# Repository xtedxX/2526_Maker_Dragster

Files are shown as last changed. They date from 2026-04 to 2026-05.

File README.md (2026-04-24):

# 🏎️ DRAGSTER — Maker Option Project

**A fully custom brushless electric dragster built from scratch: custom PCB, STM32 firmware, 3D-printed chassis and Bluetooth telemetry.**







---

## 📋 Table of Contents

- [Project Overview](#project-overview)
- [System Architecture](#system-architecture)
- [Project Structure](#project-structure)
- [Electronic Design](#electronic-design)
- [Software](#software)
- [3D Modelling and Mechanical Aspect](#3d-modelling-and-mechanical-aspect)
- [Known Issues](#known-issues)

---

## 🚀 Project Overview

This project was carried out as part of the **Maker Option** at school. The goal was to design and build a functional brushless electric dragster entirely from scratch, covering every aspect of the engineering process:

- Custom **4-layer PCB** designed in KiCad
- **STM32G431CBU6** microcontroller firmware written in C with STM32CubeIDE
- **Bluetooth** remote control and telemetry via HC-05
- **3D-printed** chassis and mechanical parts designed in Onshape
- **Brushless motor** driven by a commercial ESC via PWM

---

## 🏗️ System Architecture

### 💡 System Block Diagram

The dragster architecture follows a centralized embedded system design with the STM32G431CBU6 microcontroller managing all peripherals, sensor data acquisition, motor control, and wireless communications.

System Diagram

**Key Subsystems:**
- **Flight Computer**: STM32G431CBU6 (ARM Cortex-M4 @ 170 MHz)
- **Sensor Suite**: MMA8452Q 3-axis accelerometer (I²C interface)
- **Human Interface**: TC1602A 16×2 LCD display + WS2812B RGB LED
- **Communications**: HC-05 Bluetooth 2.0 module (UART interface)
- **Motor Control**: Robitronic Razer Ten ESC with built-in BEC driving 3000kV BLDC motor
- **Power**: LiPo 3S (11.1V) → ESC BEC (5V) → Würth 173950378 LDO (3.3V)

### 🔌 Electrical Schematic Overview

The electrical design emphasizes clean power distribution and proper signal isolation between high-current motor traces and sensitive analog sensors.

Electrical Schematic

**Power Distribution:**
- **11.1V LiPo Battery** → **ESC** (Robitronic Razer Ten with built-in BEC)
- **ESC BEC Output (5V @ 3A)** → Würth 173950378 LDO → **3.3V Logic**
- Motor receives 11.1V directly from battery through ESC
- Separate power planes for motor and logic to minimize EMI

**Signal Integrity:**
- I²C bus: 4.7kΩ pull-ups, 400 kHz operation
- UART: 3.3V logic levels, 9600 baud
- PWM: 50 Hz for ESC, 800 kHz for WS2812B
- SWD debug: dedicated JTAG connector

### 🔩 Mechanical Assembly Overview

The mechanical design prioritizes low center of gravity, rear-wheel drive power transfer, and straight-line stability.

Mechanical Assembly

**Component Mounting:**
- **Main Chassis**: Flat PLA plate (base structure)
- **Motor Mount**: Rear bracket aligned with drive pulley
- **PCB Mounting**: Center position for balanced weight distribution
- **Wheel Configuration**: Larger rear wheels for traction, smaller front for steering

---

## 📁 Project Structure

```
DRAGSTER/
│
├── 📖 README.md                        # This file
│
├── 🖼️ IMG/                             # Photos of the physical build
│   ├── dragster_assembled.jpg          # Final assembled dragster
│   ├── system_diagram.svg              # System block diagram
│   ├── electrical_schematic.svg        # Electrical schematic
│   ├── mechanical_assembly.svg         # Mechanical assembly diagram
│   ├── pcb_3d_top.png                  # KiCad 3D render top
│   ├── pcb_3d_bottom.png               # KiCad 3D render bottom
│   ├── pcb_real_top.jpg                # Real PCB top view
│   ├── pcb_real_bottom.jpg             # Real PCB bottom view
│   ├── corps_3d.png                    # Dragster body 3D render
│   ├── support_moteur_3d.png           # Motor mount 3D render
│   ├── support_roues_3d.png            # Wheel axle support 3D render
│   └── guide_roues_3d.png             # Lateral wheel guide 3D render
│
├── 📐 CAO/                             # CAD files and design resources
│   ├── DRAGSTER_Cube_MX/               # STM32CubeMX pin configuration project
│   │   └── DRAGSTER_Cube_MX.ioc        # CubeMX IOC file (pin mapping)
│   ├── DRAGSTER_PCB/                   # KiCad PCB project
│   │   ├── DRAGSTER.kicad_pcb          # PCB layout
│   │   ├── DRAGSTER.kicad_sch          # Schematic
│   │   └── ...
│   └── DRAGSTER_3D/                    # Onshape STL exports
│       ├── Corps.stl                   # Dragster body
│       ├── Support_Moteur.stl          # Motor mount
│       ├── Support_roues.stl           # Camshaft / wheel axle support
│       └── Guide_roues.stl             # Lateral wheel guide
│
└── 💻 DRAGSTER_FIRMWARE/               # STM32CubeIDE project
    └── DRAGSTER/
        ├── Core/
        │   ├── Src/
        │   │   ├── main.c              # Application entry point
        │   │   ├── bldc_esc.c          # ESC / brushless motor driver
        │   │   ├── hc05_bt.c           # Bluetooth driver + command parser
        │   │   ├── mma8452q.c          # Accelerometer driver
        │   │   ├── tc1602a_lcd.c       # LCD driver
        │   │   └── ws2812.c            # NeoPixel LED driver
        │   └── Inc/
        │       ├── bldc_esc.h
        │       ├── hc05_bt.h
        │       ├── mma8452q.h
        │       ├── tc1602a_lcd.h
        │       └── ws2812.h
        └── ...
```

---

## ⚡ Electronic Design

### 🔗 Component Selection & Justification

| Component | Model | Specifications | Engineering Rationale |
|---|---|---|---|
| **Microcontroller** | STM32G431CBU6 | ARM Cortex-M4, 170 MHz, UFQFPN48, 128 KB Flash, 32 KB RAM, Hardware FPU | High processing speed for real-time sensor fusion and PWM generation; hardware floating-point unit accelerates velocity integration algorithms; 170 MHz provides sufficient headroom for Bluetooth protocol handling |
| **Brushless Motor** | Robitronic Razer Ten 3652 3000kV (R01230) | 3000 kV, 3652 form factor, 3S LiPo compatible, 350W max power | High kV rating provides aggressive acceleration; 3S compatibility matches battery voltage; compact 3652 size fits dragster chassis constraints |
| **ESC** | Robitronic Razer Ten ESC | PWM control 50 Hz, pulse 1–2 ms, waterproof, 60A continuous, **Built-in BEC: 5V @ 3A** | Standard RC PWM interface simplifies firmware; 60A rating provides safety margin for peak current draws; waterproof design protects against track debris; **Built-in BEC eliminates need for separate buck converter — provides 5V power rail for logic** |
| **Accelerometer** | MMA8452Q | 3-axis, 12-bit resolution, I²C interface, ±8g range, 800 Hz ODR, embedded FIFO | ±8g range captures full dragster launch dynamics; 800 Hz sampling rate prevents aliasing of high-frequency vibrations; I²C interface reduces pin count; FIFO buffer offloads MCU during burst acceleration |
| **LCD Display** | TC1602A | 16×2 characters, HD44780 controller, 4-bit parallel interface, 5V tolerant | Industry-standard HD44780 ensures driver compatibility; 4-bit mode saves GPIO pins; 16×2 layout accommodates speed/peak display; high contrast for outdoor visibility |
| **Bluetooth Module** | HC-05 | Bluetooth 2.0 Classic SPP, UART interface, 9600 baud default, 3.3V logic, 10m range | Serial Port Profile (SPP) enables simple UART passthrough; 9600 baud sufficient for telemetry bandwidth; 3.3V logic compatible with STM32 GPIO; widely supported by PC/Android terminals |
| **RGB LED** | WS2812B | Addressable RGB, 800 kHz PWM protocol, 5V supply, single-wire control | Addressable interface allows dynamic status indication; single-wire protocol minimizes pin usage; built-in PWM drivers offload MCU; **Note**: 5V requirement conflicts with 3.3V board supply |
| **Battery** | LiPo 3S | 11.1V nominal (12.6V max, 9V min), 2200 mAh capacity, 25C discharge | 3S voltage matches motor/ESC specifications; 2200 mAh provides ~5 min runtime at full throttle; 25C discharge rating (55A burst) exceeds motor peak current |
| **Voltage Regulator (LDO)** | Würth 173950378 | Input: 4.5–5.5V, Output: 3.3V @ 1A, Dropout: 150mV, Low noise | Converts 5V from ESC BEC to 3.3V logic level; low dropout ensures stable 3.3V even when 5V sags; low noise critical for ADC and analog sensors; compact SOT-23-5 package |
| **Polarity Protection** | SQ2389CES-T1_GE3 | P-channel MOSFET, -20V Vds, -8A Id, 25 mΩ Rds(on) | Low on-resistance minimizes voltage drop; automotive-grade robustness; **Note**: Not populated on final board |

### 📋 PCB Design

The PCB was designed entirely from scratch using **KiCad 9.0**. Before layout, **STM32CubeMX** was used to plan and verify peripheral pin assignments, ensuring no resource conflicts.

**CubeMX Configuration File:**
```
CAO/DRAGSTER_Cube_MX/DRAGSTER_Cube_MX.ioc
```

#### PCB Specifications

| Parameter | Value | Engineering Notes |
|---|---|---|
| **Dimensions** | 60 mm × 60 mm | Square form factor simplifies chassis mounting; fits within dragster width constraints |
| **Layer Count** | 4 layers | Minimum for proper power/ground plane separation |
| **Layer 1 (Top)** | Signal routing | Component-side traces, I²C/UART/GPIO |
| **Layer 2 (Inner)** | Ground plane | Solid copper pour, minimal voids, return path for all signals |
| **Layer 3 (Inner)** | Power plane | Split 5V/3.3V regions, thermal relief for vias |
| **Layer 4 (Bottom)** | Signal routing | Secondary traces, connector breakouts |
| **Copper Weight** | 1 oz (35 µm) | Standard weight, adequate for logic-level currents |
| **Min Track/Gap** | 6/6 mil (0.15 mm) | JLCPCB standard capability |
| **Via Size** | 0.3 mm drill, 0.6 mm pad | Standard via, thermal/signal transfer |
| **Manufacturer** | JLCPCB | 4-day turnaround, cost-effective for prototyping |

**Stackup Advantages:**
- Dedicated ground plane (Layer 2) provides low-impedance return path for high-speed PWM signals
- Power plane (Layer 3) reduces supply inductance and decoupling requirements
- Four-layer design enables controlled impedance routing (not critical at these speeds but improves margin)
- Ground plane shields sensitive I²C traces from motor PWM noise

#### KiCad 3D Renders

**Top Layer (Component Side):**

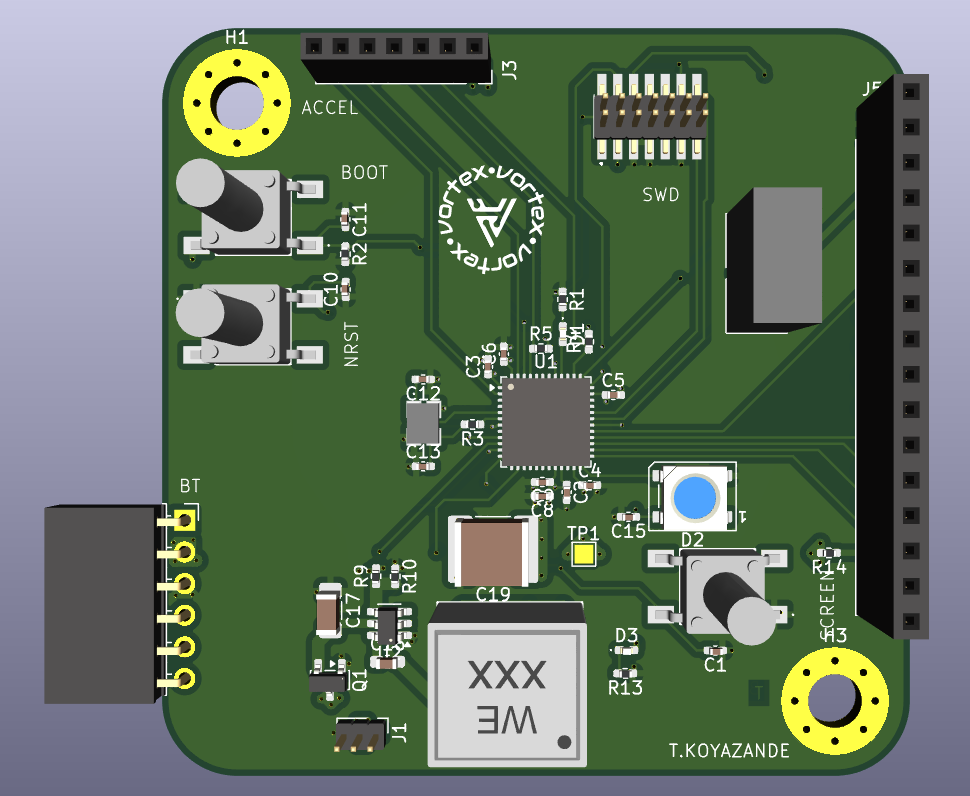
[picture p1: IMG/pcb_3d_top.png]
PCB 3D render — top


**Component Placement:**
- **Center**: STM32G431CBU6 (UFQFPN-48 package, 7×7 mm)
- **Top-Left**: MMA8452Q accelerometer (QFN-16, oriented with X-axis parallel to chassis)
- **Top-Right**: Würth 173950378 LDO regulator (5V to 3.3V conversion)
- **Bottom-Left**: HC-05 Bluetooth module connector (6-pin header)
- **Bottom-Right**: LCD interface connector (8-pin header: 4 data + RS/E/VCC/GND)
- **Right Edge**: ESC PWM output (3-pin servo connector) + 5V BEC input from ESC
- **Left Edge**: JTAG/SWD debug header (10-pin Cortex standard)

**Bottom Layer (Connector Side):**

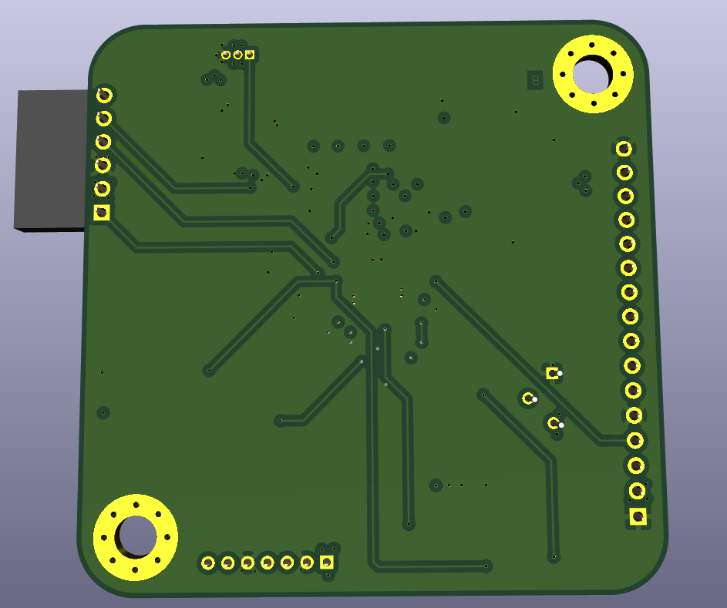
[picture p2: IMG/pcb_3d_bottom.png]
PCB 3D render — bottom


**Features:**
- Battery input connector (JST XH 2S/3S balance plug compatible)
- NeoPixel LED footprint (currently unpopulated due to voltage mismatch)
- Reverse polarity protection MOSFET footprint (designed but not populated)
- Ground test points for oscilloscope probing

#### Real PCB Photos

**Fabricated Top Layer:**

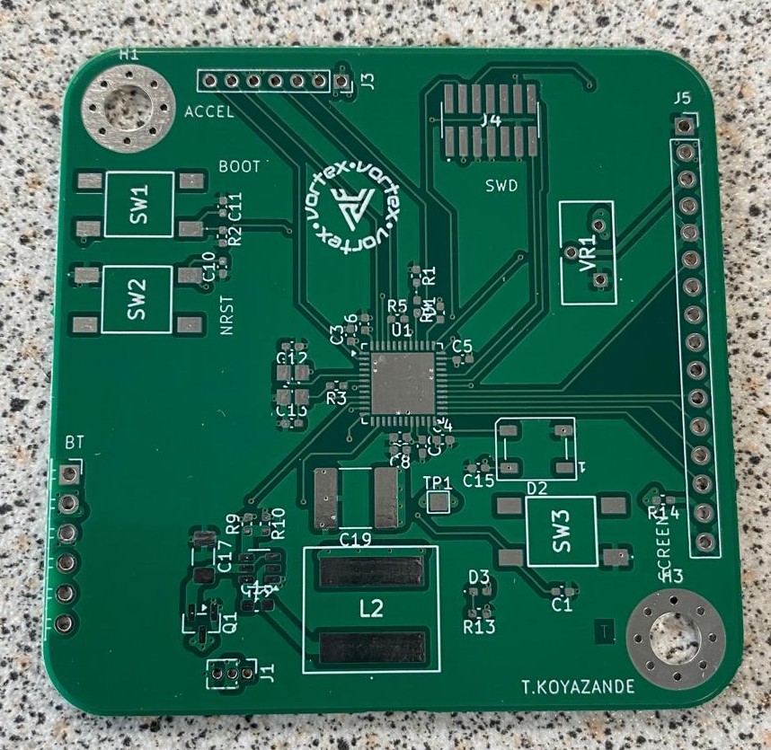
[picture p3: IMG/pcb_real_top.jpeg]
Real PCB — top


**Fabricated Bottom Layer:**

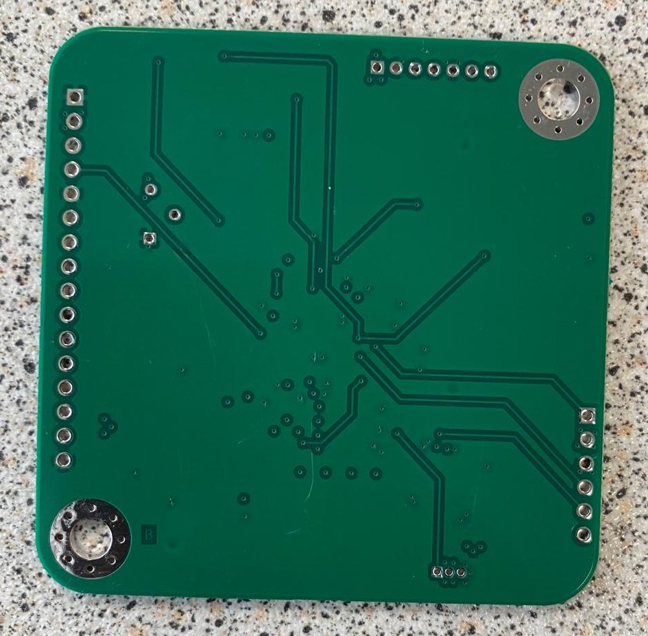
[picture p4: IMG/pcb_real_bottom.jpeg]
Real PCB — bottom


**Fully Assembled Board:**

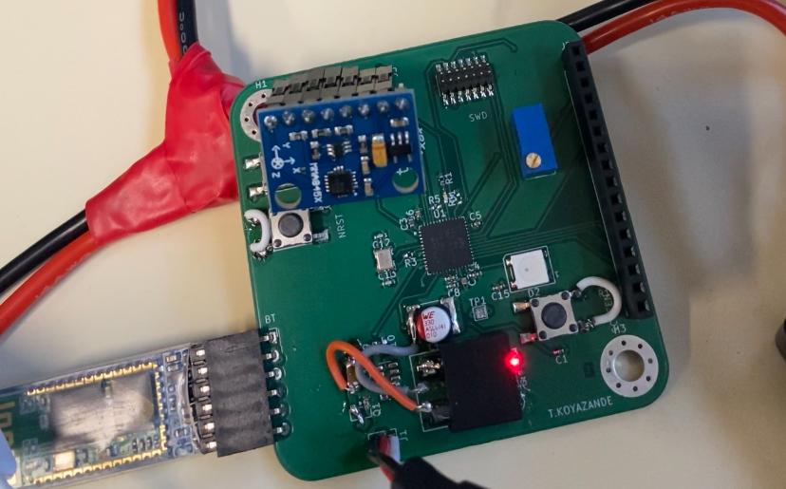
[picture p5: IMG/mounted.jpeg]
Real PCB — with components


**Assembly Notes:**
- All SMD components hand-soldered using hot air rework station and an oven
- UFQFPN-48 package required careful alignment and flux application
- 0402 resistors/capacitors used for space efficiency
- Through-hole connectors added last to prevent mechanical stress during SMD soldering

---

## 💻 Software

### 📐 Pin Assignment — STM32CubeMX

Before writing any firmware, **STM32CubeMX** was used to configure the clock tree, assign peripheral pins, and verify that no resource conflicts existed. This tool generates the HAL initialization code automatically, ensuring consistency between hardware and software.

**CubeMX Configuration:**
```
CAO/DRAGSTER_Cube_MX/DRAGSTER_Cube_MX.ioc
```

#### Peripheral Pin Mapping

| Peripheral | Pins | Function | Configuration |
|---|---|---|---|
| **I2C1** | PA15 (SCL), PB7 (SDA) | MMA8452Q accelerometer communication | 400 kHz fast mode, 7-bit addressing, repeated start enabled |
| **USART2** | PA2 (TX), PA3 (RX) | HC-05 Bluetooth module | 9600 baud, 8N1, RX interrupt-driven |
| **USART1** | PA9 (TX), PA10 (RX) | ST-Link debug console output | 115200 baud, 8N1, polling mode |
| **TIM3 CH1** | PA6 | ESC PWM signal generation | 50 Hz (20 ms period), 1-2 ms pulse width |
| **TIM2 CH4** | PB11 | WS2812B NeoPixel DMA PWM | 800 kHz bit encoding via DMA circular buffer |
| **GPIO Output** | PA8 | LCD RS (Register Select) | Push-pull, high speed |
| **GPIO Output** | PC6 | LCD E (Enable strobe) | Push-pull, high speed |
| **GPIO Output** | PB12–PB15 | LCD DB4–DB7 (4-bit data) | Push-pull, high speed |
| **GPIO Input** | PC13 | Accelerometer INT1 (data ready) | Pull-down, EXTI interrupt (unused in polling implementation) |
| **GPIO Input** | PB9 | Accelerometer INT2 (motion detect) | Pull-down, EXTI interrupt (unused) |

**Clock Configuration:**
- **HSE**: 16 MHz external crystal oscillator
- **PLL**: Input 16 MHz → PLLM /1 → VCO 680 MHz → PLLN ×85 → PLLP /4 → **170 MHz System Clock**
- **APB1**: 85 MHz (TIM2/3 at 170 MHz after prescaler doubling)
- **APB2**: 170 MHz (high-speed peripherals)
- **AHB**: 170 MHz (CPU, DMA, memory)

---

### 🗂️ Firmware Architecture

```
DRAGSTER_FIRMWARE/DRAGSTER/Core/
│
├── Src/
│   ├── main.c              # Application entry point and main loop
│   ├── bldc_esc.c          # Brushless motor ESC PWM driver
│   ├── hc05_bt.c           # HC-05 Bluetooth UART driver and command parser
│   ├── mma8452q.c          # MMA8452Q I²C accelerometer driver
│   ├── tc1602a_lcd.c       # TC1602A LCD parallel interface driver
│   └── ws2812.c            # WS2812B NeoPixel DMA PWM driver (non-functional)
│
└── Inc/
    ├── bldc_esc.h          # ESC API and configuration macros
    ├── hc05_bt.h           # Bluetooth handle and command definitions
    ├── mma8452q.h          # Accelerometer register map and API
    ├── tc1602a_lcd.h       # LCD command macros and API
    └── ws2812.h            # NeoPixel color encoding and API
```

---

### 📦 Software Module Descriptions

#### `main.c` — Application Entry Point

**Responsibilities:**
- HAL library initialization
- System clock configuration (170 MHz)
- Peripheral initialization (GPIO, DMA, timers, UARTs, I²C)
- Boot sequence orchestration
- Main event loop execution

**Boot Sequence:**
1. `HAL_Init()` — Initialize HAL library and configure SysTick timer
2. `SystemClock_Config()` — Configure PLL to achieve 170 MHz system clock
3. `MX_GPIO_Init()` — Configure GPIO pins (LCD control, LEDs, debug)
4. `MX_DMA_Init()` — Initialize DMA channels for TIM2 PWM (NeoPixel)
5. `MX_I2C1_Init()` — Configure I²C1 at 400 kHz for accelerometer
6. `MX_TIM2_Init()` — Configure TIM2 for 800 kHz NeoPixel PWM
7. `MX_TIM3_Init()` — Configure TIM3 for 50 Hz ESC PWM
8. `MX_USART1_UART_Init()` — Configure debug UART at 115200 baud
9. `MX_USART2_UART_Init()` — Configure Bluetooth UART at 9600 baud
10. **`HAL_TIM_PWM_Start(&htim3, TIM_CHANNEL_1)`** — **CRITICAL**: Start ESC PWM immediately (ESC expects signal within 2 seconds of power-on)
11. `LCD_Splash()` — Display boot logo on LCD ("DRAGSTER v1.0")
12. `MMA8452Q_Init()` — Initialize accelerometer (±8g range, 800 Hz ODR)
13. `BT_Init()` — Initialize Bluetooth driver and enable RX interrupt
14. `ESC_Init()` — Execute ESC arming sequence (~8 seconds, blocking)
15. **Main Loop** — `while(1)` calls `BT_Task()` and updates LCD with accelerometer data

**Main Loop Structure:**
```c
while (1) {
    BT_Task();  // Process Bluetooth commands, send telemetry
    
    // Read accelerometer X-axis
    float accel_x_g = MMA8452Q_ReadAccelX();
    
    // Integrate to compute speed (trapezoidal rule)
    static float prev_accel = 0.0f;
    float dt = 0.01f;  // 100 Hz loop rate (approximate)
    speed_ms += (accel_x_g + prev_accel) / 2.0f * 9.81f * dt;
    prev_accel = accel_x_g;
    
    // Update LCD display
    LCD_PrintSpeed(speed_ms * 3.6f);  // Convert m/s to km/h
    LCD_PrintPeakSpeed(peak_speed_kmh);
    
    HAL_Delay(10);  // 100 Hz update rate
}
```

---

#### `bldc_esc.c` / `bldc_esc.h` — ESC PWM Driver

**Purpose:** Generate precise 50 Hz PWM signals to control the Robitronic Razer Ten ESC, which in turn drives the brushless motor.

**Timer Configuration:**
- **Timer**: TIM3 Channel 1 (PA6)
- **Prescaler (PSC)**: 169 → Timer clock = 170 MHz / 170 = **1 MHz** (1 tick = 1 µs)
- **Auto-Reload (ARR)**: 19999 → Period = 20000 µs = **20 ms** = **50 Hz**
- **Pulse Width Range**: 1000–2000 µs (standard RC servo range)

**Verified PWM Values:**

| Compare Value | Pulse Width | Duty Cycle | Throttle | ESC Behavior |
|---|---|---|---|---|
| `199` | 200 µs | 1% | 0% | Minimum throttle (motor off) |
| `2999` | 3000 µs | 15% | 50% | Neutral (used during arming only) |
| `9999` | 10000 µs | 50% | 100% | Maximum throttle (full power) |

**Note:** ESC interprets pulse widths, not duty cycle percentages. The unusual mapping (200 µs = 0%, 10000 µs = 100%) is ESC-specific.

**ESC Arming Sequence** (empirically determined):
1. **Step 1** (4 s): Send 3000 µs pulse → ESC beeps twice, recognizes calibration range
2. **Step 2** (2 s): Send 200 µs pulse → ESC beeps three times, arms motor controller
3. **Step 3** (2 s): Send 3000 µs pulse → ESC ready, motor can now be controlled

**Total arming time**: ~8 seconds (blocking operation during boot)

**API Functions:**

| Function | Parameters | Description |
|---|---|---|
| `ESC_Init()` | `void` | Executes the 3-step arming sequence. PWM must already be running via `HAL_TIM_PWM_Start()` before calling. Blocking for 8 seconds. |
| `ESC_SetThrottlePct(pct)` | `uint8_t pct` (0–100) | Sets throttle as percentage. Internally maps to 200–10000 µs pulse range via linear interpolation. |
| `ESC_SetPulse(pulse_us)` | `uint16_t pulse_us` | Directly sets PWM compare value (200–10000 µs). Bypasses percentage mapping for advanced control. |
| `ESC_Stop()` | `void` | Immediately sets throttle to 0% (200 µs pulse). Emergency stop function. |
| `ESC_RampTo(pct, step_ms)` | `uint8_t pct`, `uint16_t step_ms` | Gradually increases or decreases throttle to target percentage with specified step delay. Blocking function. Prevents abrupt torque changes that could flip the dragster. |

**Configuration Macros** (`bldc_esc.h`):
```c
#define ESC_PULSE_MIN_US    199U    // 0% throttle (actually 200 µs, off-by-one from rounding)
#define ESC_PULSE_MAX_US    9999U   // 100% throttle (10000 µs)
#define ESC_PULSE_NEUTRAL   2999U   // 50% neutral (3000 µs, arming only)
```

**Safety Features:**
- Bounds checking on all throttle commands (clipped to 0–100%)
- Exponential ramping option to prevent wheel spin
- Emergency stop function callable from interrupt context

---

#### `hc05_bt.c` / `hc05_bt.h` — Bluetooth UART Driver

**Purpose:** Manage bidirectional communication with the HC-05 Bluetooth module over USART2, implementing a command/response protocol for remote control and telemetry streaming.

**UART Configuration:**
- **Peripheral**: USART2 (PA2 TX, PA3 RX)
- **Baud Rate**: 9600 (HC-05 default, configurable via AT commands)
- **Data Format**: 8N1 (8 data bits, no parity, 1 stop bit)
- **RX Mode**: Interrupt-driven (single-byte interrupt per character)
- **TX Mode**: Blocking (polling until transmit complete)

**Driver Architecture:**

The Bluetooth driver operates in a non-blocking state machine model, where `BT_Task()` is called from the main loop at ~100 Hz. This function:
1. **Processes received commands** from a circular buffer filled by UART RX interrupt
2. **Reads accelerometer** and tracks peak g-force
3. **Streams telemetry** if enabled (live acceleration data)
4. **Sends heartbeat** every 1 second to maintain connection awareness

**Important**: Motor control is **entirely manual** — there is no autonomous throttle logic. The dragster only moves when explicitly commanded via `THROTTLE` or `BURST` commands.

**Command Protocol:**

Commands are ASCII strings terminated by newline (`\n` or `\r\n`). Responses are prefixed with `$` for easy parsing.

**Downlink (Phone/PC → MCU):**

| Command | Parameters | Description | Response |
|---|---|---|---|
| `PING` | None | Connectivity test | `$HB` (heartbeat) |
| `INFO` | None | Request firmware version and config | `$INFO,FW=1.0,RANGE=8G,ODR=800Hz,BAUD=9600` |
| `STREAM,ON` | None | Enable continuous accelerometer streaming | `$ACK,STREAM,ON` → `$ACC,<g>` every 100 ms |
| `STREAM,OFF` | None | Disable accelerometer streaming | `$ACK,STREAM,OFF` |
| `THROTTLE,<pct>` | `pct`: 0–100 | Set motor throttle to percentage (sustained) | `$ACK,THROTTLE,<pct>` |
| `MOTOR,STOP` | None | Emergency stop (throttle to 0%) | `$ACK,MOTOR,STOP` |
| `BURST,<pct>,<ms>` | `pct`: 0–100, `ms`: duration | Run motor at percentage for milliseconds, then stop | `$ACK,BURST,<pct>,<ms>` → `$ACK,BURST,DONE` |
| `RESET` | None | Reset peak g-force tracker to zero | `$ACK,RESET` |

**Uplink (MCU → Phone/PC, unsolicited):**

| Frame | Frequency | Description |
|---|---|---|
| `$HB` | 1 Hz | Heartbeat indicating MCU is alive |
| `$ACC,<g>` | 10 Hz (when streaming enabled) | Live X-axis acceleration in g-forces (e.g., `$ACC,2.34`) |
| `$PEAK,<g>` | Event-driven | New peak g-force detected (e.g., `$PEAK,4.12`) |
| `$ERR,<code>` | Event-driven | Error notification (e.g., `$ERR,I2C_FAIL`) |

**Connection Setup:**

**Windows:**
1. Pair HC-05 in Bluetooth settings (PIN: `1234` or `0000`)
2. Note assigned COM port (e.g., `COM5`)
3. Open **Tera Term**, select Serial, configure 9600 baud 8N1
4. Send commands, observe responses

**Android:**
1. Install **Serial Bluetooth Terminal** by Kai Morich
2. Pair HC-05 in Android Bluetooth settings
3. Connect in app, send commands via text input

**iOS:**
- Not supported — HC-05 uses Bluetooth Classic SPP profile, which iOS restricts to MFi-certified accessories

**Example Terminal Session:**
```
[BT] HC-05 driver initialized (USART2 @ 9600 baud)
$INFO,FW=1.0,RANGE=8G,ODR=800Hz,BAUD=9600
$HB
$HB
> PING
$HB
> STREAM,ON
$ACK,STREAM,ON
$ACC,0.0021
$ACC,-0.0013
$ACC,0.0008
> STREAM,OFF
$ACK,STREAM,OFF
> THROTTLE,30
$ACK,THROTTLE,30
[Motor now running at 30%]
> MOTOR,STOP
$ACK,MOTOR,STOP
> BURST,50,2000
$ACK,BURST,50,2000
[Motor runs at 50% for 2 seconds]
$ACK,BURST,DONE
```

**Implementation Notes:**
- Commands are case-sensitive
- Comma-separated parameters (no spaces)
- Response timeout: 100 ms (if no `$ACK` received, command was malformed)
- Circular buffer size: 256 bytes (handles burst command streams)

---

#### `mma8452q.c` / `mma8452q.h` — Accelerometer Driver

**Purpose:** Interface with the MMA8452Q 3-axis accelerometer over I²C to measure dragster launch dynamics.

**I²C Configuration:**
- **Bus**: I2C1 (PA15 SCL, PB7 SDA)
- **Speed**: 400 kHz (I²C Fast Mode)
- **Addressing**: 7-bit address `0x1D` (SA0 pin grounded)
- **Protocol**: Repeated start required for register reads (per datasheet)

**Sensor Configuration:**
- **Range**: ±8g (configurable to ±2g/±4g, but dragster launches exceed 4g)
- **Resolution**: 12-bit left-justified (4096 counts = 8g → 1 LSB ≈ 0.002g)
- **Output Data Rate**: 800 Hz (1.25 ms sample period)
- **Operating Mode**: Active polling (interrupt pins unused in current implementation)

**Register Map (Subset):**

| Address | Name | Description |
|---|---|---|
| `0x00` | STATUS | Data ready flags |
| `0x01` | OUT_X_MSB | X-axis data [11:4] |
| `0x02` | OUT_X_LSB | X-axis data [3:0] in bits [7:4] |
| `0x0E` | XYZ_DATA_CFG | Range selection (±2g/±4g/±8g) |
| `0x2A` | CTRL_REG1 | Active mode, ODR selection |

**Data Format:**
- 12-bit signed integer, left-justified in 16-bit register pair
- Raw value must be right-shifted by 4 bits before sign extension
- Conversion: `g = (int16_t)(raw >> 4) / 2048.0f` (for ±8g range)

**API Functions:**

| Function | Return Type | Description |
|---|---|---|
| `MMA8452Q_Init()` | `HAL_StatusTypeDef` | Configures sensor to ±8g range, 800 Hz ODR, active mode. Returns `HAL_OK` on success. |
| `MMA8452Q_ReadAccelX()` | `float` | Reads X-axis acceleration in g-forces. Blocking I²C transaction (~250 µs at 400 kHz). |
| `MMA8452Q_ReadAccelXYZ(float* x, float* y, float* z)` | `void` | Reads all three axes (unused in dragster application, provided for completeness). |

**Coordinate System:**
- **X-axis**: Parallel to dragster forward motion (primary measurement axis)
- **Y-axis**: Lateral (perpendicular to motion, should remain near 0g)
- **Z-axis**: Vertical (gravity component, ~1g when stationary)

**Performance:**
- I²C transaction time: ~250 µs (6 bytes at 400 kHz)
- Main loop calls `ReadAccelX()` at 100 Hz → 2.5% bus utilization
- No DMA used (low bandwidth, simple implementation)

---

#### `tc1602a_lcd.c` / `tc1602a_lcd.h` — LCD Display Driver

**Purpose:** Drive the TC1602A 16×2 character LCD in 4-bit parallel mode for real-time speed visualization.

**Interface:**
- **Mode**: 4-bit data bus (DB4–DB7 only, DB0–DB3 unused)
- **Control Pins**: RS (Register Select), E (Enable), R/W tied to GND (write-only)
- **Timing**: GPIO bit-banging with `HAL_Delay()` for all timing (no hardware PWM)

**GPIO Pin Mapping:**

| LCD Pin | STM32 Pin | Function |
|---|---|---|
| RS | PA8 | Register Select (0 = command, 1 = data) |
| E | PC6 | Enable strobe (falling edge latches data) |
| DB4 | PB12 | Data bit 4 (LSB in 4-bit mode) |
| DB5 | PB13 | Data bit 5 |
| DB6 | PB14 | Data bit 6 |
| DB7 | PB15 | Data bit 7 (MSB in 4-bit mode) |

**Initialization Sequence** (HD44780 standard):
1. Wait 15 ms after power-on
2. Send `0x03` three times (function set to 8-bit mode, required for 4-bit mode entry)
3. Send `0x02` (switch to 4-bit mode)
4. Send `0x28` (4-bit mode, 2 lines, 5×8 font)
5. Send `0x0C` (display on, cursor off, blink off)
6. Send `0x06` (auto-increment cursor, no display shift)
7. Send `0x01` (clear display)

**Display Layout:**
```
+--------------------+
| Speed:   87.3 km/h |   ← Row 0: Current speed
| Peak:   102.5 km/h |   ← Row 1: Peak speed
+--------------------+
```

**API Functions:**

| Function | Parameters | Description |
|---|---|---|
| `LCD_Init()` | `void` | Executes HD44780 initialization sequence. Blocking for ~50 ms. |
| `LCD_Clear()` | `void` | Clears display and returns cursor to home. Blocking for 2 ms. |
| `LCD_SetCursor(row, col)` | `uint8_t row`, `uint8_t col` | Positions cursor (row: 0-1, col: 0-15). |
| `LCD_Print(str)` | `const char* str` | Prints null-terminated string at current cursor position. |
| `LCD_PrintSpeed(speed_kmh)` | `float speed_kmh` | Formats and prints "Speed: XXX.X km/h" to row 0. |
| `LCD_PrintPeakSpeed(peak_kmh)` | `float peak_kmh` | Formats and prints "Peak: XXX.X km/h" to row 1. |
| `LCD_Splash()` | `void` | Displays boot logo ("DRAGSTER v1.0 / Ready..."). |

**Timing Notes:**
- All timing uses `HAL_Delay()` (millisecond resolution) rather than busy-wait loops
- Enable pulse width: 1 ms (datasheet minimum: 450 ns, large margin for GPIO jitter)
- Command execution time: 2 ms (conservative, covers all HD44780 commands)
- Works reliably at 170 MHz system clock (validated empirically)

**Speed Calculation:**
Velocity is computed via **trapezoidal integration** of X-axis acceleration:
```c
v(t+Δt) = v(t) + [ a(t) + a(t+Δt) ] / 2 × Δt
```
Where:
- `a(t)` = acceleration in m/s² (converted from g: `accel_g × 9.81`)
- `Δt` = 0.01 s (100 Hz main loop)
- `v(0)` = 0 m/s (reset on boot or via `RESET` command)

Conversion to km/h: `speed_kmh = speed_ms × 3.6`

**Peak Speed Tracking:**
- Peak value updated whenever current speed exceeds previous peak
- Peak persists across runs until manual reset via Bluetooth `RESET` command
- Displayed with 0.1 km/h precision

---

#### `ws2812.c` / `ws2812.h` — NeoPixel LED Driver

**Purpose:** Drive a single WS2812B addressable RGB LED using DMA-driven PWM for status indication.

**Protocol:**
- **Timing**: 800 kHz bit clock (1.25 µs per bit)
- **Encoding**: PWM duty cycle (0 code: 30%, 1 code: 60%)
- **Data Format**: 24-bit GRB (8 bits green, 8 bits red, 8 bits blue)
- **Reset**: >50 µs low period between frames

**Timer Configuration:**
- **Timer**: TIM2 Channel 4 (PB11)
- **Prescaler**: 0 → Timer clock = 170 MHz
- **ARR**: 213 → PWM period = 1.26 µs ≈ **800 kHz**
- **DMA**: Circular mode, 24 compare values (one per bit)

**PWM Encoding Table:**

| Bit Value | Pulse Width | Duty Cycle | TIM2 Compare Value |
|---|---|---|---|
| `0` | ~0.4 µs | 30% | 64 |
| `1` | ~0.8 µs | 60% | 128 |

**API Functions:**

| Function | Parameters | Description |
|---|---|---|
| `WS2812_Init()` | `void` | Starts TIM2 PWM with DMA transfer. |
| `WS2812_SetColor(r, g, b)` | `uint8_t r`, `uint8_t g`, `uint8_t b` | Sets LED color (0–255 per channel). Updates DMA buffer and triggers transfer. |
| `WS2812_SetRGB(rgb)` | `uint32_t rgb` | Sets color from packed 24-bit value (0xRRGGBB). |
| `WS2812_Off()` | `void` | Turns LED off (all channels to 0). |

**Current Status:**
⚠️ **Non-functional** — WS2812B requires 5V supply (datasheet: 4.5–5.5V typical, 3.5V absolute minimum). PCB routes 3.3V to LED power pin, which is below the minimum operating voltage. LED does not illuminate at 3.3V.

**Fix for Next Revision:**
- Add 3.3V → 5V level shifter (e.g., 74HCT125) on PWM data line
- Route 5V from ESC BEC output to LED VDD
- Alternatively, replace WS2812B with APA102 (tolerates 3.3V logic)

---

### ⚙️ System Behavior Summary

| Phase | Duration | Description | Visual Indicators |
|---|---|---|---|
| **Boot** | ~8 s | HAL init → peripheral init → LCD splash → accelerometer init → BT init → **ESC arming sequence** → ready | LCD: "DRAGSTER v1.0 / Arming ESC..." → "Ready" |
| **Idle** | Continuous | Main loop running, BT sending `$HB` every 1 s, motor at 0% | LCD: "Speed: 0.0 km/h / Peak: 0.0 km/h" |
| **Controlled Run** | User-defined | Motor commanded via `THROTTLE` or `BURST`, accelerometer logging, LCD updating | LCD: Live speed climbing, peak updating |
| **Streaming Mode** | Until disabled | BT transmitting `$ACC` frames at 10 Hz (100 ms intervals) | Terminal: Continuous g-force readout |

**Autonomous Features:**
- **None** — Dragster has no autonomous throttle control
- Motor only runs when explicitly commanded via Bluetooth
- No automatic braking or collision avoidance (intentional for Maker Option project)

---

## 🔩 3D Modelling and Mechanical Aspect

All mechanical components were designed in **Onshape** (cloud-based parametric CAD) and fabricated via FDM 3D printing. STL export files are located in `CAO/DRAGSTER_3D/`.

### Design Constraints

- **Material**: PLA (polylactic acid thermoplastic)
- **Print Settings**: 0.2 mm layer height, 20% infill, no supports
- **Weight Budget**: <500 g total (chassis + electronics + battery)
- **Mounting**: M3 screws and heat-set brass inserts

---

### Dragster Body — `CAO/DRAGSTER_3D/Corps.stl`

**Function:** Main structural chassis providing mounting points for all subsystems.

**Specifications:**
- **Dimensions**: 250 mm (L) × 120 mm (W) × 15 mm (H)
- **Mass**: 85 g (PLA, 20% infill)
- **Features**:
  - PCB mounting bosses with M3 threaded inserts (4× corners)
  - Battery retention clip (velcro strap channel)
  - Rear motor mount alignment pins
  - Front wheel axle supports (press-fit 3 mm rod)

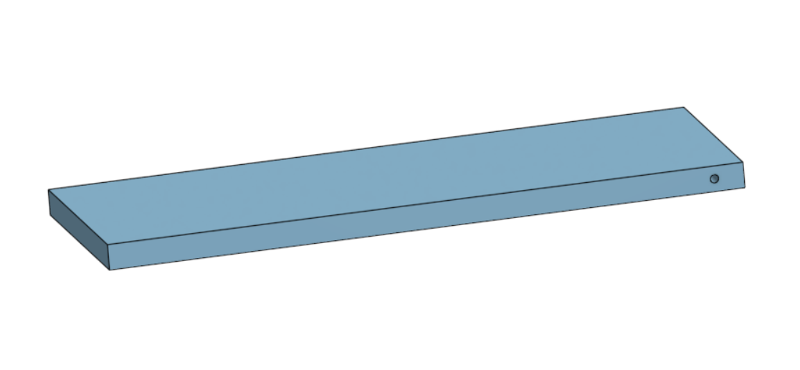
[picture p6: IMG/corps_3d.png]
Dragster body — 3D render


**Design Notes:**
- Flat base plate distributes weight evenly
- Ribbed structure on underside increases rigidity without adding mass
- Open-top design allows easy access to PCB for debugging

---

### Motor Mount — `CAO/DRAGSTER_3D/Support_Moteur.stl`

**Function:** Secure the brushless motor to the rear chassis, maintaining alignment with the drive pulley.

**Specifications:**
- **Material**: PLA, 40% infill (higher strength for motor vibration)
- **Mass**: 18 g
- **Motor Bolt Pattern**: 16 mm × 25 mm (standard 3652 motor can)
- **Mounting**: 2× M3 screws into chassis

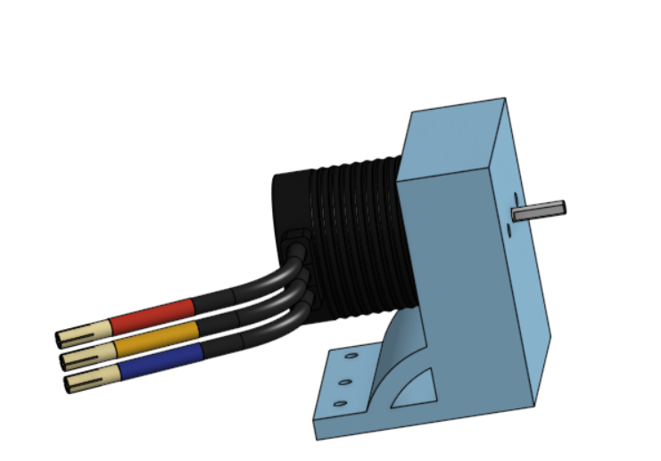
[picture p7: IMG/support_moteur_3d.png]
Motor mount — 3D render


**Design Notes:**
- Angled bracket positions motor shaft parallel to rear axle
- Clearance for GT2 timing belt (6 mm wide)
- Ventilation slots for motor cooling airflow

---

### Wheel Axle Support — `CAO/DRAGSTER_3D/Support_roues.stl`

**Function:** Support the rear axle shaft and driven pulley, transmitting motor torque to the wheels.

**Specifications:**
- **Material**: PLA, 30% infill
- **Mass**: 12 g
- **Axle Diameter**: 3 mm steel rod (press-fit bearings)
- **Features**:
  - Dual ball bearing seats (608ZZ, 8 mm ID × 22 mm OD)
  - GT2 pulley mount (16 teeth, 5 mm bore)
  - Wheel retention clip slots

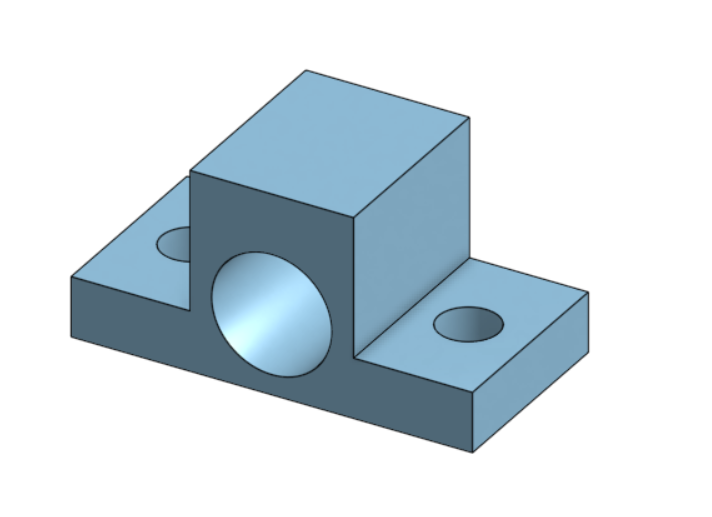
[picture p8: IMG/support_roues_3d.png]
Wheel axle support — 3D render


**Design Notes:**
- Bearings reduce friction and prevent axle wobble
- Pulley positioned for optimal belt tension
- Symmetric design allows left/right interchangeability

---

### Lateral Wheel Guide — `CAO/DRAGSTER_3D/Guide_roues.stl`

**Function:** Prevent lateral drift during acceleration, ensuring straight-line motion.

**Specifications:**
- **Material**: PLA, 20% infill
- **Mass**: 8 g
- **Design**: Cylindrical channel aligned with front wheel
- **Mounting**: Friction fit into chassis slot

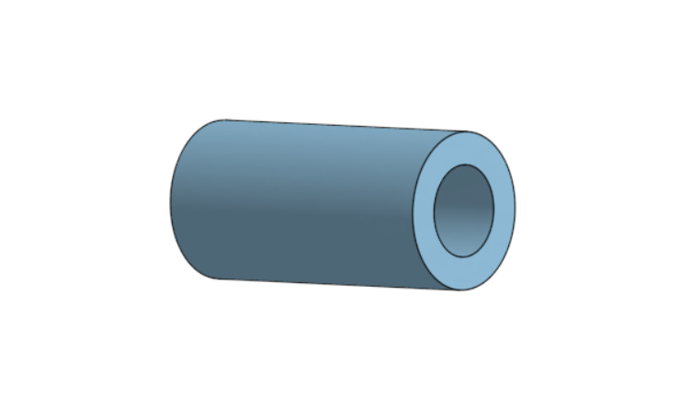
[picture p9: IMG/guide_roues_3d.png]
Lateral wheel guide — 3D render


**Design Notes:**
- Acts as a passive guide rail on straight test tracks
- Low friction surface (PLA on smooth floor)
- Removable for open-track testing

---

### Drivetrain Overview

**Power Transmission:**
```
BLDC Motor (3000 kV, 11.1V) 
    → Pinion Pulley (10 teeth, 5 mm bore)
    → GT2 Timing Belt (158-2GT, 6 mm wide)
    → Driven Pulley (16 teeth, 3 mm bore)
    → Rear Axle (3 mm steel rod)
    → Rear Wheels (50 mm diameter)
```

**Gear Ratio:**
- Motor pulley: 10 teeth
- Axle pulley: 16 teeth
- **Reduction ratio**: 16:10 = **1.6:1**

**Speed Calculation:**
- Motor @ 11.1V: 3000 kV × 11.1V = 33,300 RPM (no-load)
- Estimated loaded speed: ~20,000 RPM (accounting for torque)
- Wheel speed: 20,000 RPM / 1.6 = **12,500 RPM**
- Linear speed: (12,500 RPM × π × 0.05 m) / 60 = **32.7 m/s = 118 km/h** (theoretical max)

**Wheel Configuration:**
- **Front wheels**: 30 mm diameter (small for low rolling resistance)
- **Rear wheels**: 50 mm diameter (large for traction and top speed)
- Dragster-style weight distribution: ~30% front, 70% rear

**Braking:**
- **None** — Dragster coasts to a stop after motor cutoff
- Stopping distance from 10 m/s: ~15 m (rolling friction only)
- No parachute or friction brake (future improvement)

---

### Assembled Dragster

**Final Assembly:**

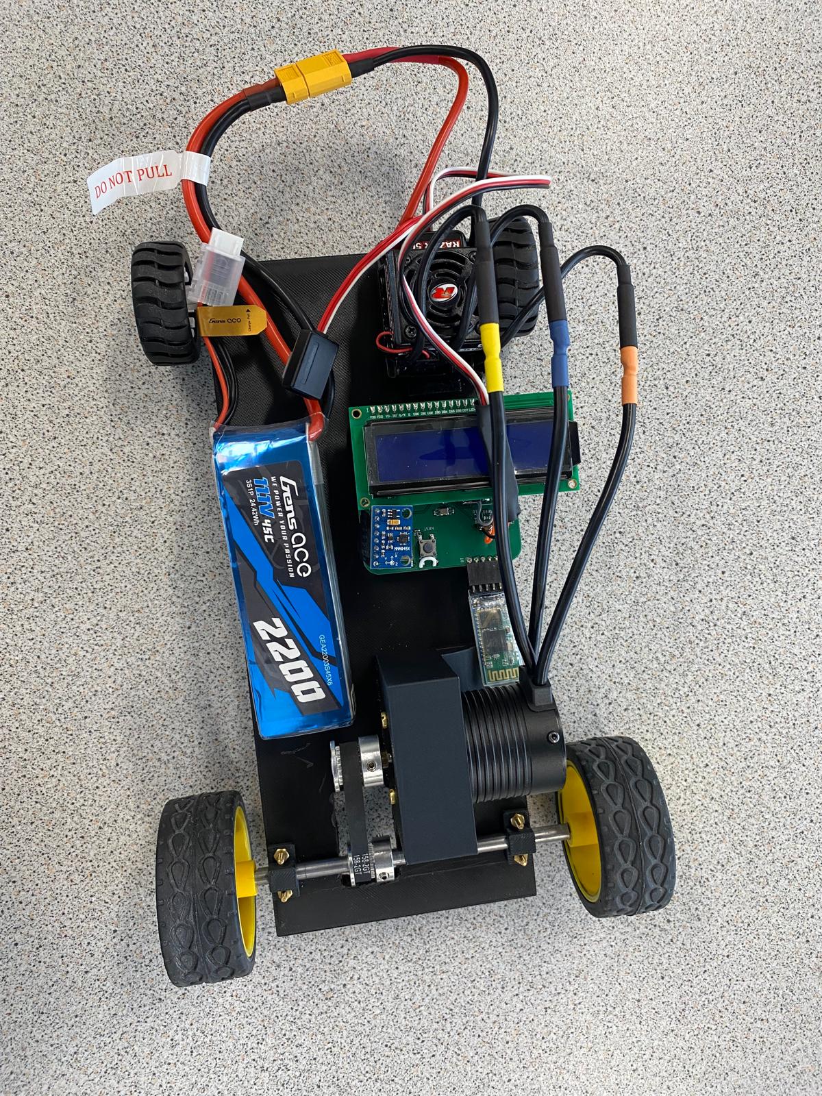
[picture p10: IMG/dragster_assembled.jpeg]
Fully assembled dragster


**Component Integration:**
- PCB mounted center-chassis (low center of gravity)
- Battery secured with velcro strap (quick-change capability)
- Motor aligned with drive belt (minimal slack)
- LCD visible from operator position
- HC-05 Bluetooth antenna oriented upward (optimal range)

**Mass Breakdown:**
- Chassis + mounts: 123 g
- PCB + components: 45 g
- Battery (3S 2200 mAh): 180 g
- Motor + ESC: 85 g
- Wheels + axles: 40 g
- **Total**: 473 g ✅ (under 500 g target)

---

## 📝 Known Issues

| Issue | Status | Impact | Planned Fix |
|---|---|---|---|
| **NeoPixel not lighting** | ⚠️ Known | WS2812B wired to 3.3V (requires 5V minimum) | PCB v2: Add 74HCT125 level shifter + route 5V from ESC BEC |
| **Reverse polarity protection** | ⚠️ Not populated | SQ2389CES-T1_GE3 footprint present but component not soldered | Populate MOSFET in next build (low priority, battery connector keyed) |
| **iOS Bluetooth incompatibility** | ❌ By design | HC-05 uses Classic SPP (iOS restricts to MFi accessories) | No fix planned — use Android or Windows for control |
| **Accelerometer drift** | 🔄 Minor | Velocity integration accumulates error over long runs (±5% after 30 s) | Implement periodic GPS reset or IMU fusion (out of scope) |
| **Belt tension adjustment** | 🔄 Minor | No tensioner mechanism — belt must be manually adjusted | Design spring-loaded motor mount for PCB v2 |

---

## 🎓 Lessons Learned

### PCB Design
- **Always verify component footprints** in 3D before ordering to catch errors early
- **Design for testability**: Add test points on all power rails and critical signals
- **Plan for mistakes**: Include unpopulated footprints for optional features (e.g., polarity protection)
- **Understand your power architecture**: The ESC BEC provides 5V, eliminating the need for a separate buck converter

### Firmware
- **Start ESC PWM immediately** after timer init — ESCs have <2 s timeout for signal detection
- **Use HAL_Delay() for bit-banging** at high system clocks (170 MHz) — busy-wait loops are error-prone
- **Implement command echo** in Bluetooth protocol for debugging (helps catch parser bugs)

### Mechanical
- **Print test brackets first** before committing to full chassis (motor mount v1 was 2 mm too narrow)
- **Heat-set inserts** are superior to threaded PLA (threads strip after 3–4 assembly cycles)
- **Larger wheels in rear** dramatically improve traction (initial design had equal-diameter wheels, frequent wheelspin)

---

## 🚀 Future Improvements

### Hardware v2
- [ ] Fix NeoPixel voltage (add level shifter + 5V rail)
- [ ] Add current sensing (INA219 on motor power line for energy consumption logging)
- [ ] Integrate 9-DOF IMU (MPU9250) for drift correction and 3D orientation tracking
- [ ] Add microSD card slot for offline data logging

### Firmware v2
- [ ] Implement Kalman filter for accelerometer + gyroscope fusion
- [ ] Add adaptive PID control for target speed maintenance
- [ ] Bluetooth Low Energy (BLE) support for iOS compatibility (nRF52 module)
- [ ] Over-the-air (OTA) firmware updates via Bluetooth

### Mechanical v2
- [ ] Design aerodynamic body shell (reduce drag coefficient)
- [ ] Add deployable parachute brake (solenoid-actuated)
- [ ] Implement active suspension (servo-controlled camber adjustment)
- [ ] Switch to brushless outrunner motor (higher efficiency, lower heat)

---

**School:** ENSEA — Maker Option Project  
**Academic Year:** 2025–2026  
**Target MCU:** STM32G431CBU6 @ 170 MHz  
**Development Tools:** STM32CubeIDE, KiCad 9.0, Onshape  
**Control Interface:** Tera Term (Windows) / Serial Bluetooth Terminal (Android)  

---

*Built with ❤️ for the Maker option*

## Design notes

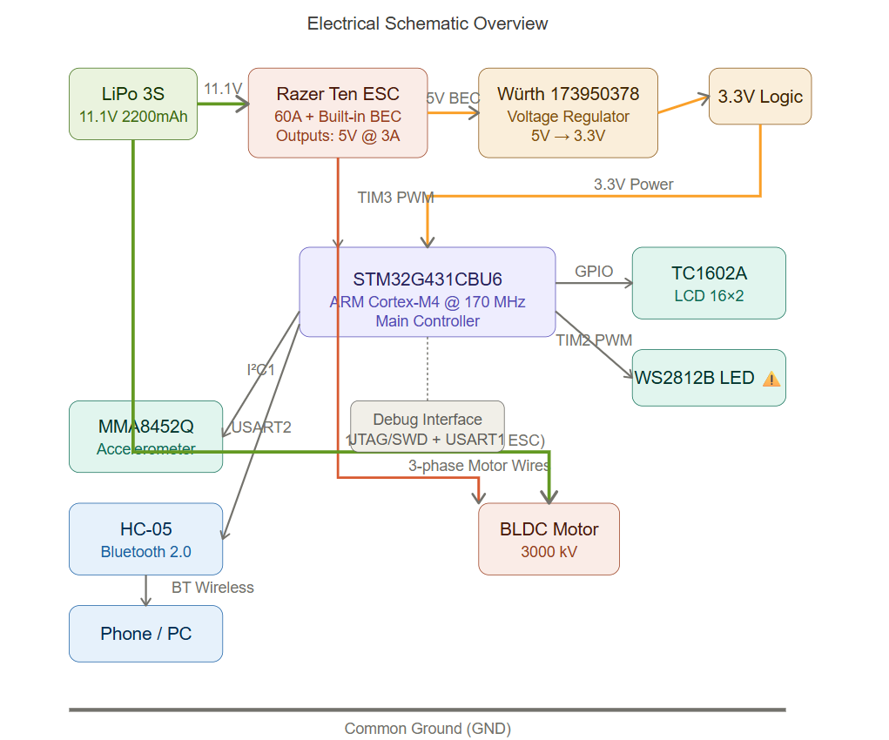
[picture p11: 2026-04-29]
IMG/electrical_schematic.png

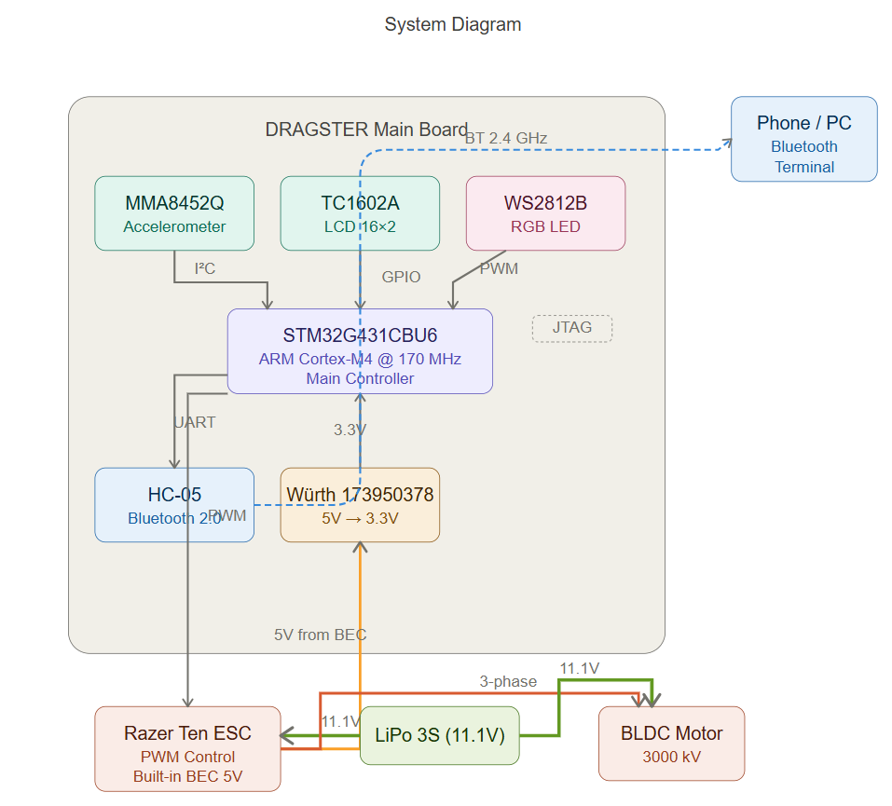
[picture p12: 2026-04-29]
IMG/system_diagram.png

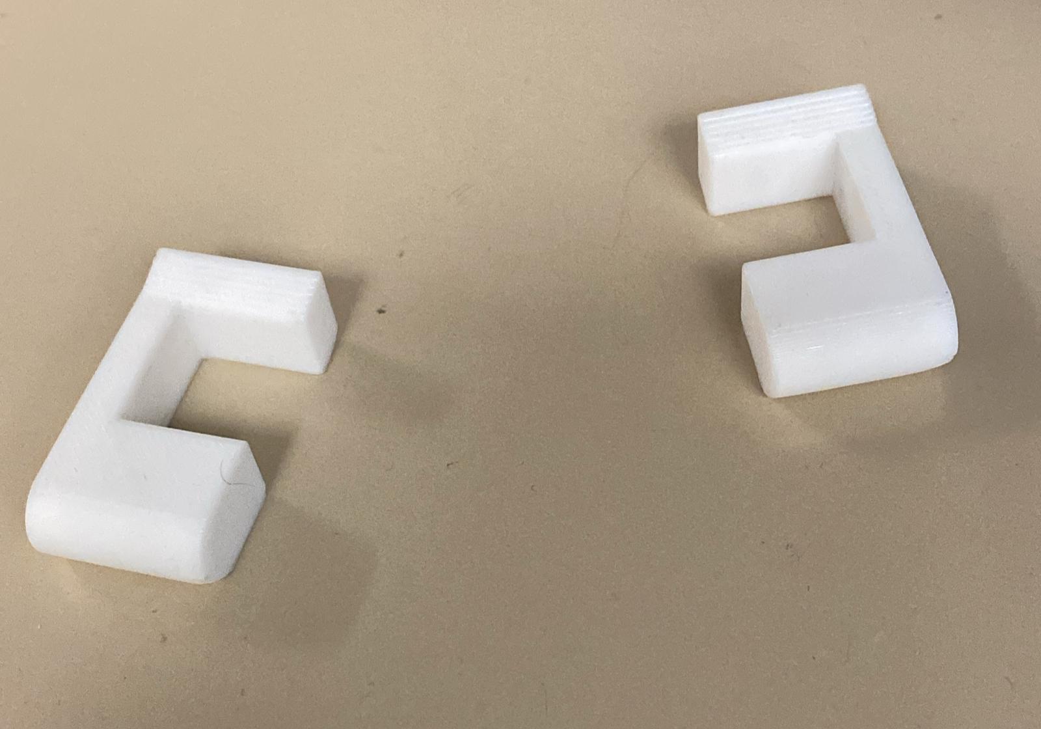
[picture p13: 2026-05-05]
TD/TD_ONSHAPE/IMPR3D.jpeg

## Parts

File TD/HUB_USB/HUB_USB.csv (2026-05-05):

Reference | Qty | Value | DNP | Exclude from BOM | Exclude from Board | Footprint | Datasheet | MPN
C1 | 1 | 10u |  |  |  | Capacitor_SMD:C_0402_1005Metric | ~ | GRM155R60J106ME18D
C2 | 1 | 100n |  |  |  | Capacitor_SMD:C_0402_1005Metric | ~ | GXT155R71E104KE01D
C3,C11 | 2 | 1u |  |  |  | Capacitor_SMD:C_0603_1608Metric | ~ | KGM15BS60J105KT
C4,C5 | 2 | 18p |  |  |  | Capacitor_SMD:C_0402_1005Metric | ~ | VJ0402D180FXCAJ
C6,C7,C8,C9 | 4 | 100u |  |  |  | Capacitor_SMD:C_1206_3216Metric | ~ | KGM31HR50J107MU
C10 | 1 | 470u |  |  |  | Capacitor_SMD:CP_Elec_6.3x9.9 | ~ | APZ0609471M010R
D1,D2,D3,D4,D5 | 5 | LED_Small |  |  |  | LED_SMD:LED_0603_1608Metric | ~ | LSM0603453V
F1 | 1 | 0 |  |  |  | Fuse:Fuse_1206_3216Metric | ~ | SF-1206SA2000R-2
H1,H2,H3,H4 | 4 | MountingHole_Pad |  | Exclure de la Liste du Matériel |  | MountingHole:MountingHole_2.7mm_M2.5_Pad_Via | ~
J1,J2,J3,J6,J7 | 5 | USB_C_Receptacle_USB2.0_16P |  |  |  | Connector_USB:USB_C_Receptacle_Palconn_UTC16-G | https://www.usb.org/sites/default/files/documents/usb_type-c.zip | 217179-0001
J4,J5 | 2 | Conn_01x01_Pin |  |  |  | TestPoint:TestPoint_Pad_D1.5mm | ~ | CPG-62-TH-TR
J8 | 1 | Conn_02x07_Odd_Even |  |  |  | Connector_PinHeader_1.27mm:PinHeader_2x07_P1.27mm_Vertical_SMD | ~ | 10129381-914001BLF
R1,R3,R4,R5,R6,R7,R8,R9,R10,R11 | 10 | 5k1 |  |  |  | Resistor_SMD:R_0603_1608Metric | ~ | TNPW06035K11BYEN
R2 | 1 | 4k7 |  |  |  | Resistor_SMD:R_0402_1005Metric | ~ | RCA04024K70JNED
R12,R13 | 2 | 56k |  |  |  | Resistor_SMD:R_0805_2012Metric | ~ | KTR10EZPF5602
R14,R15 | 2 | 220 |  |  |  | Resistor_SMD:R_0402_1005Metric | ~ | KTR25JZPF2200
R16 | 1 | 470 |  |  |  | Resistor_SMD:R_0603_1608Metric | ~ | PTN0603E4700BST1
U1 | 1 | CH334F |  |  |  | Package_DFN_QFN:QFN-24-1EP_4x4mm_P0.5mm_EP2.7x2.7mm | https://www.wch-ic.com/downloads/file/327.html | 5997
U2,U3,U4,U5,U7 | 5 | USBLC6-2SC6 |  |  |  | Package_TO_SOT_SMD:SOT-23-6 | https://www.st.com/resource/en/datasheet/usblc6-2.pdf | USBLC6-2SC6
U6 | 1 | CH217K |  |  |  | Package_TO_SOT_SMD:SOT-23-6 |  | CH217K
Y1 | 1 | 12MHz |  |  |  | Crystal:Crystal_SMD_WE_CFPX-104-4Pin_5.0x3.2mm | ~ | 830036401

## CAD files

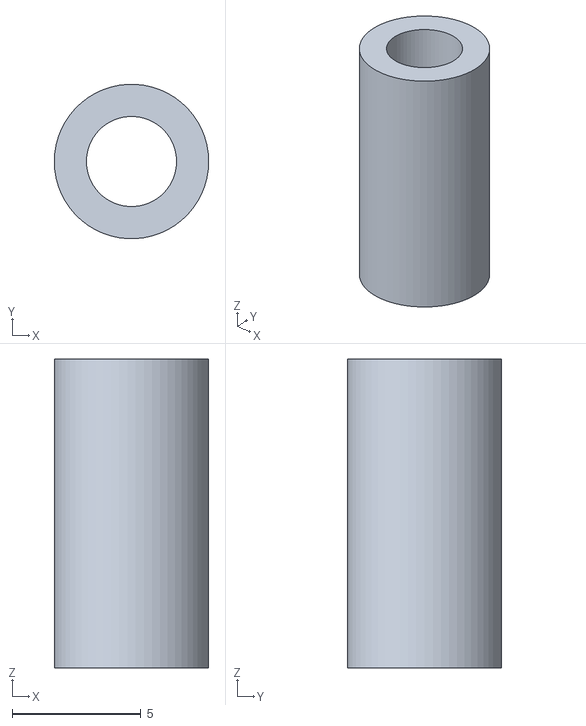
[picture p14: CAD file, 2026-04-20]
CAD/DRAGSTER_3D/Guide_Roues.stl
6.00 x 5.99 x 12.0

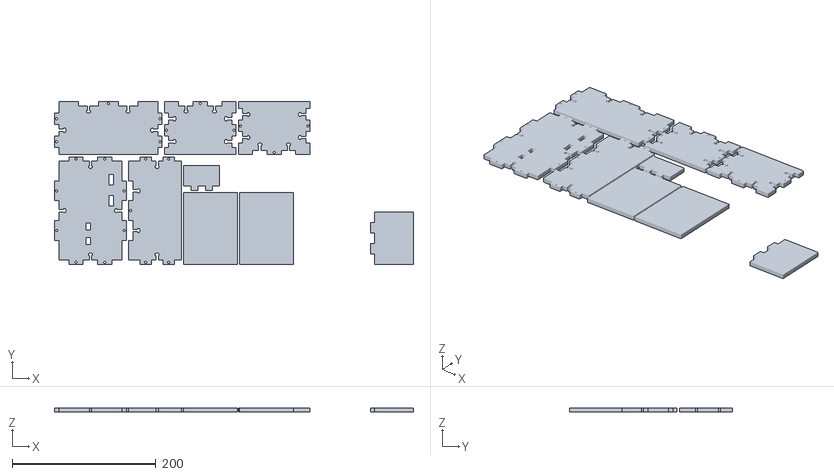
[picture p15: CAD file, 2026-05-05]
TD/TD_ONSHAPE/Useless_Box.stl
500.0 x 227.0 x 6.00

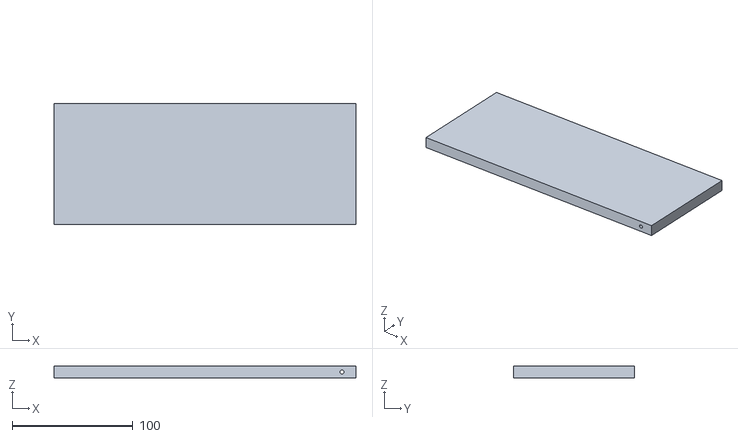
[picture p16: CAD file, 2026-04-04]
CAD/DRAGSTER_3D/Corps.stl
250.0 x 100.0 x 10.0

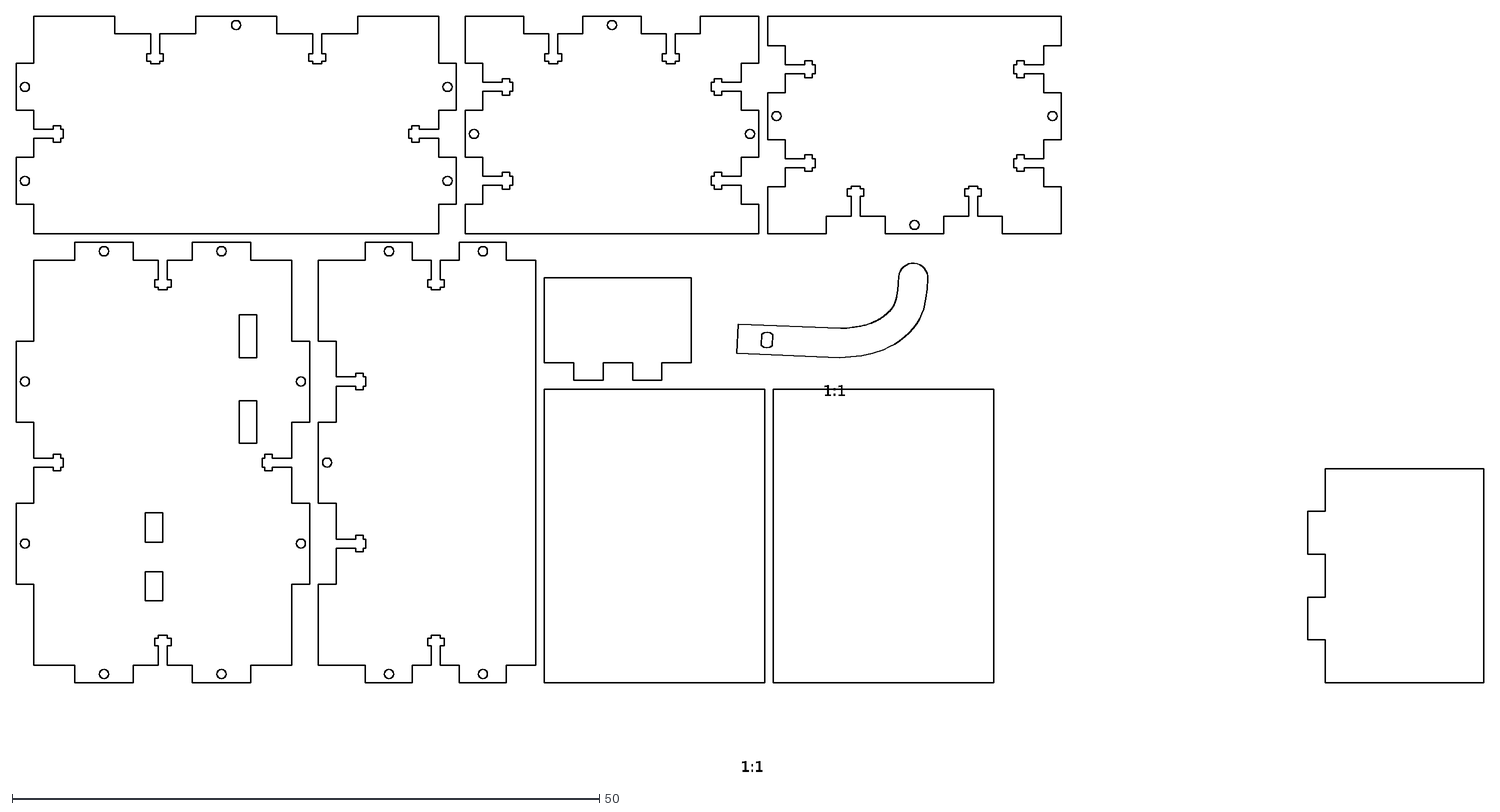
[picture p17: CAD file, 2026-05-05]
TD/TD_ONSHAPE/Drawing_Useless_Box.dxf
1:1

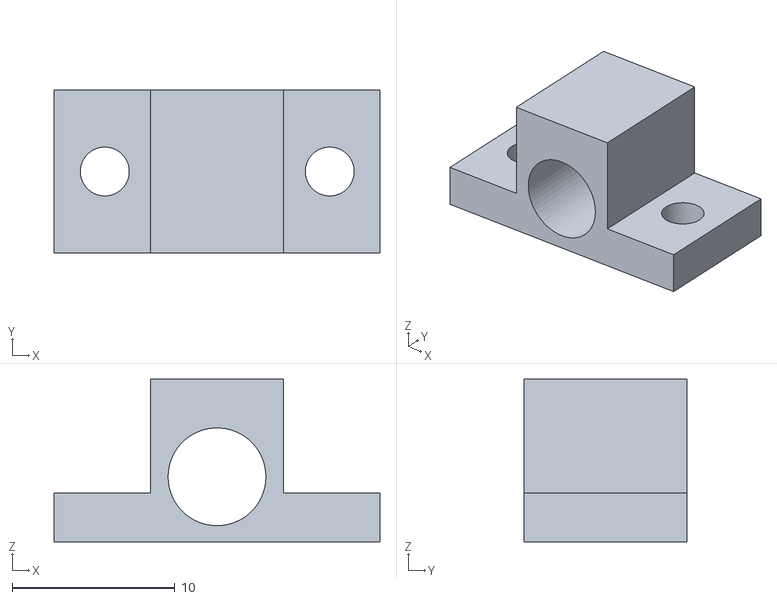
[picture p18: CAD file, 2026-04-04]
CAD/DRAGSTER_3D/Support_roues.stl
20.0 x 10.0 x 10.0

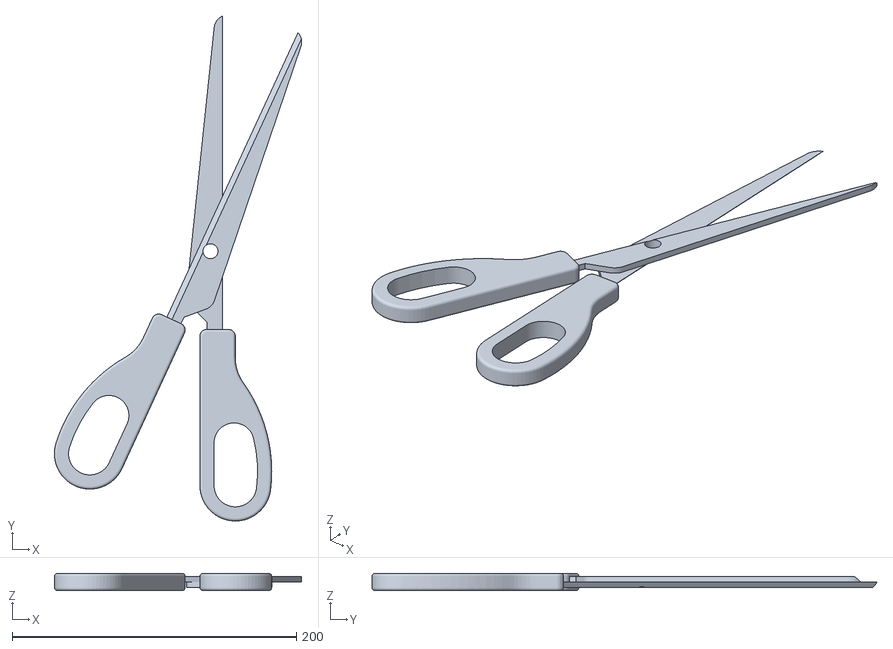
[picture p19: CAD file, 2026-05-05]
TD/TD_ONSHAPE/Exercice 3.stl
174.1 x 355.6 x 12.0

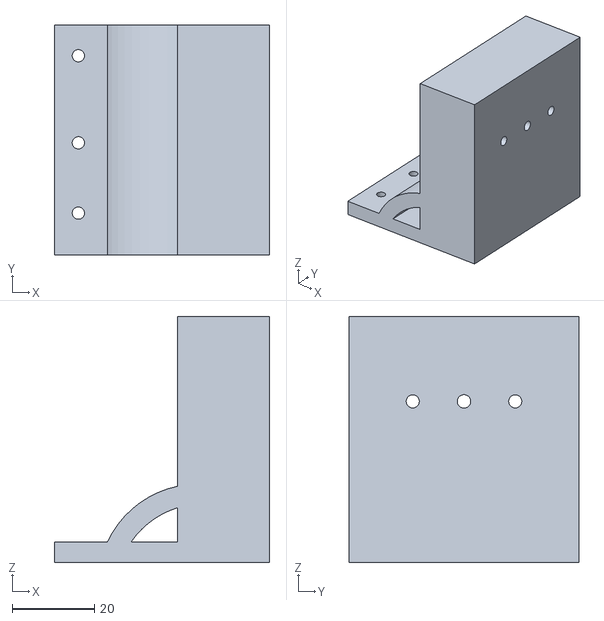
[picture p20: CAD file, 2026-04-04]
CAD/DRAGSTER_3D/Support_Moteur.stl
52.5 x 56.0 x 60.0

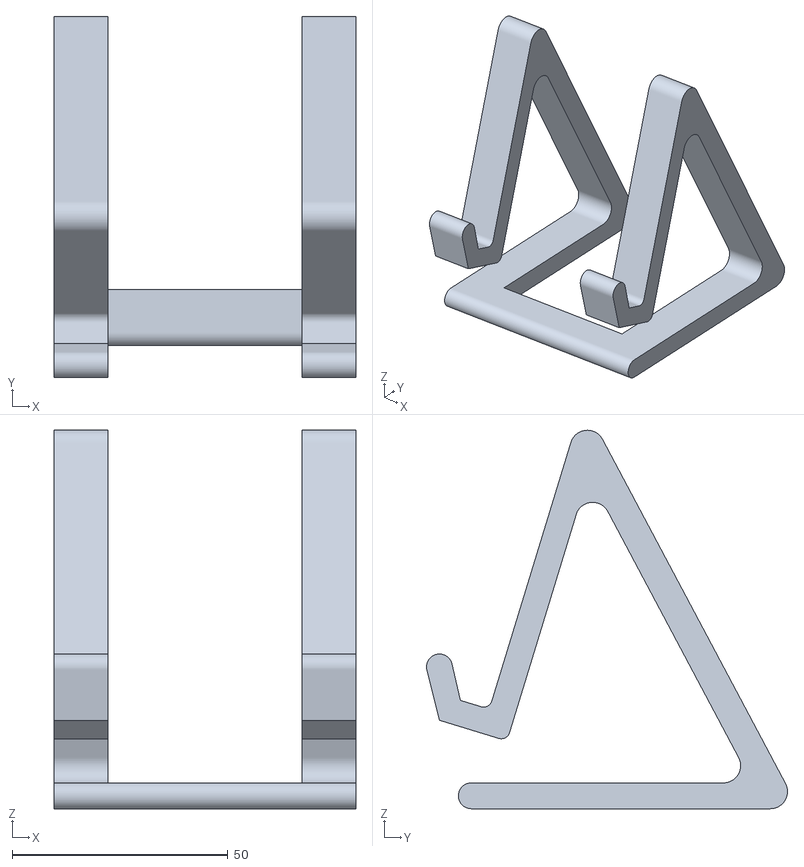
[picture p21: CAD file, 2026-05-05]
TD/TD_ONSHAPE/Exercice 2.stl
70.0 x 83.7 x 87.8

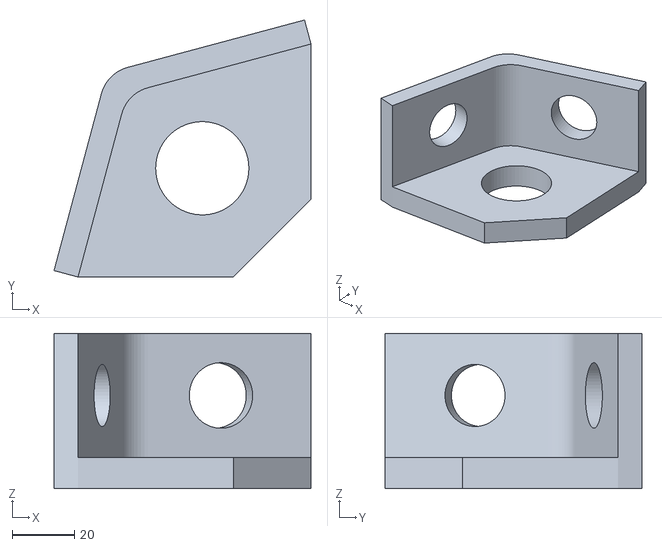
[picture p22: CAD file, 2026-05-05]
TD/TD_ONSHAPE/Exercice 1.stl
82.7 x 82.7 x 50.0

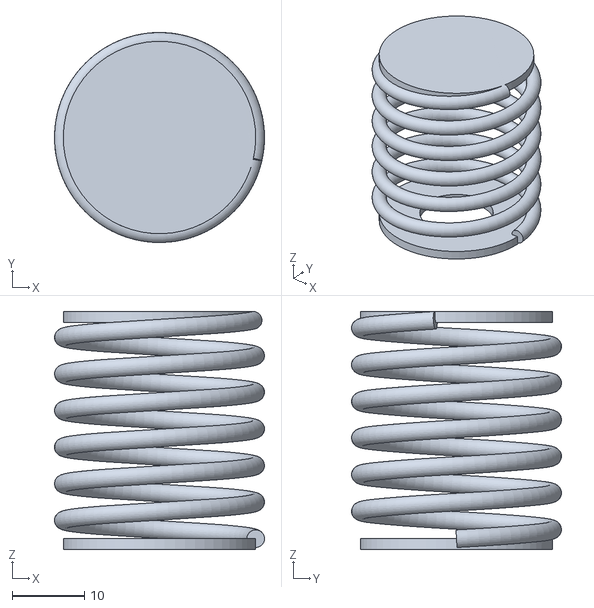
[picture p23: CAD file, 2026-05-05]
TD/TD_ONSHAPE/Exercice 5.stl
29.1 x 29.1 x 33.0

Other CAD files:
TD/TD_ONSHAPE/Exercice 4.stl

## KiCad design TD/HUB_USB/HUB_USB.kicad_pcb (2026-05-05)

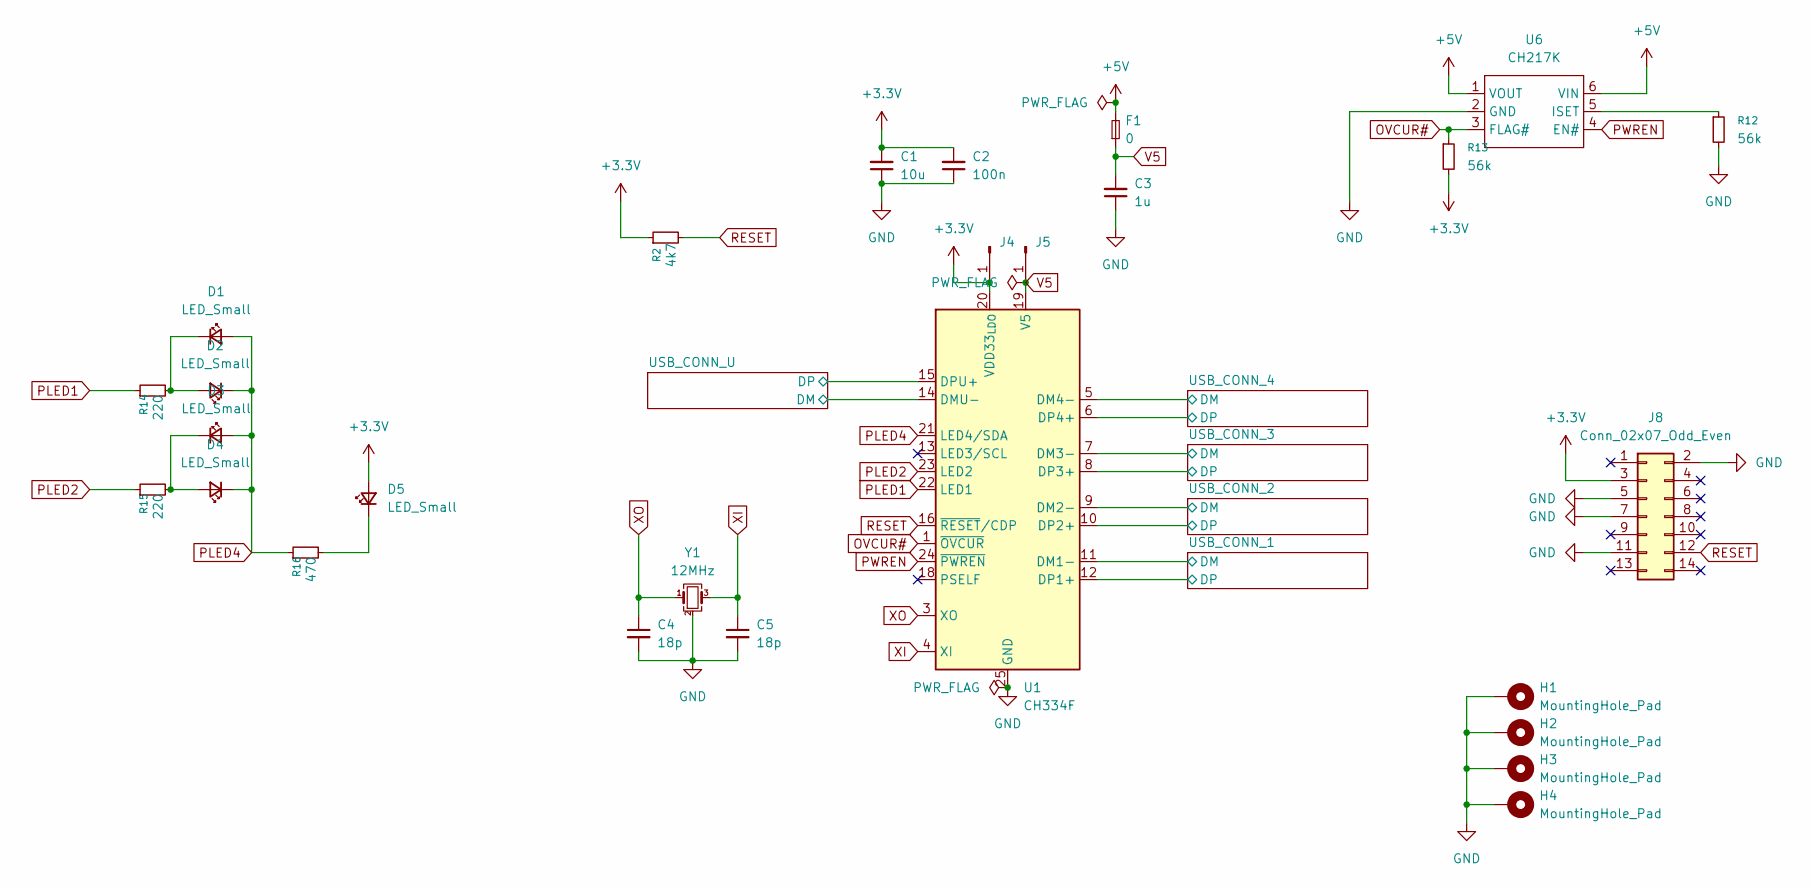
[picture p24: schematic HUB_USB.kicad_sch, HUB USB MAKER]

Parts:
C1: 10u; C_0402_1005Metric; MPN GRM155R60J106ME18D
C2: 100n; C_0402_1005Metric; MPN GXT155R71E104KE01D
C3: 1u; C_0603_1608Metric; MPN KGM15BS60J105KT
C4, C5: 18p; C_0402_1005Metric; MPN VJ0402D180FXCAJ
D1, D2, D3, D4, D5: LED_Small; LED_0603_1608Metric; MPN LSM0603453V
F1: 0; Fuse_1206_3216Metric; MPN SF-1206SA2000R-2
H1, H2, H3, H4: MountingHole_Pad; MountingHole_2.7mm_M2.5_Pad_Via
J4, J5: Conn_01x01_Pin; TestPoint_Pad_D1.5mm; MPN CPG-62-TH-TR
J8: Conn_02x07_Odd_Even; PinHeader_2x07_P1.27mm_Vertical_SMD; MPN 10129381-914001BLF
R2: 4k7; R_0402_1005Metric; MPN RCA04024K70JNED
R12, R13: 56k; R_0805_2012Metric; MPN KTR10EZPF5602
R14, R15: 220; R_0402_1005Metric; MPN KTR25JZPF2200
R16: 470; R_0603_1608Metric; MPN PTN0603E4700BST1
U1: CH334F; QFN-24-1EP_4x4mm_P0.5mm_EP2.7x2.7mm; MPN 5997
U6: CH217K; SOT-23-6; MPN CH217K
Y1: 12MHz; Crystal_SMD_WE_CFPX-104-4Pin_5.0x3.2mm; MPN 830036401

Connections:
+3.3V: C1.2, C2.2, D5.2 (A), J4.1, J8.3, R2.1, R13.2, U1.20 (VDD33_{LDO})
+5V: F1.2, U6.1 (VOUT), U6.6 (VIN); also elsewhere on the board
/USB_CONN_1/DM: U1.11 (DM1-); also elsewhere on the board
/USB_CONN_1/DP: U1.12 (DP1+); also elsewhere on the board
/USB_CONN_2/DM: U1.9 (DM2-); also elsewhere on the board
/USB_CONN_2/DP: U1.10 (DP2+); also elsewhere on the board
/USB_CONN_3/DM: U1.7 (DM3-); also elsewhere on the board
/USB_CONN_3/DP: U1.8 (DP3+); also elsewhere on the board
/USB_CONN_4/DM: U1.5 (DM4-); also elsewhere on the board
/USB_CONN_4/DP: U1.6 (DP4+); also elsewhere on the board
/USB_CONN_U/DM: U1.14 (DMU-); also elsewhere on the board
/USB_CONN_U/DP: U1.15 (DPU+); also elsewhere on the board
GND: C1.1, C2.1, C3.1, C4.2, C5.2, H1.1, H2.1, H3.1, H4.1, J8.2, J8.5, J8.7, J8.11, R12.2, U1.25 (GND), U6.2 (GND), Y1.2 (G), Y1.4 (G); also elsewhere on the board
unnamed: D1.1 (K), D2.2 (A), R14.2
unnamed: D3.1 (K), D4.2 (A), R15.2
unnamed: D5.1 (K), R16.2
unnamed: R12.1, U6.5 (ISET)
OVCUR#: R13.1, U1.1 (~OVCUR), U6.3 (FLAG#)
PLED1: R14.1, U1.22 (LED1)
PLED2: R15.1, U1.23 (LED2)
PLED4: D1.2 (A), D2.1 (K), D3.2 (A), D4.1 (K), R16.1, U1.21 (LED4/SDA)
PWREN: U1.24 (~PWREN), U6.4 (EN#)
RESET: J8.12, R2.2, U1.16 (~RESET/CDP)
V5: C3.2, F1.1, J5.1, U1.19 (V5)
XI: C5.1, U1.4 (XI), Y1.3
XO: C4.1, U1.3 (XO), Y1.1

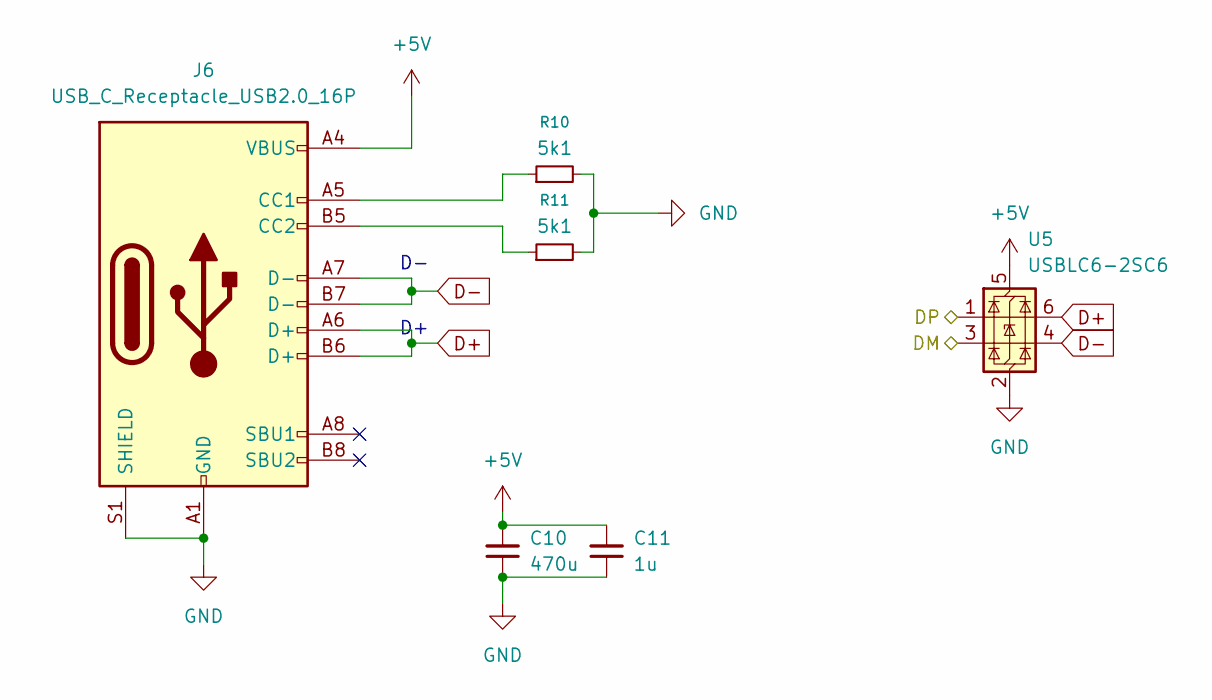
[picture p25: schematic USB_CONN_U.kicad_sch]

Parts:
C10: 470u; CP_Elec_6.3x9.9; MPN APZ0609471M010R
C11: 1u; C_0603_1608Metric; MPN KGM15BS60J105KT
J6: USB_C_Receptacle_USB2.0_16P; USB_C_Receptacle_Palconn_UTC16-G; MPN 217179-0001
R10, R11: 5k1; R_0603_1608Metric; MPN TNPW06035K11BYEN
U5: USBLC6-2SC6; SOT-23-6; MPN USBLC6-2SC6

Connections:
+5V: C10.2, C11.2, J6.A4 (VBUS), J6.A9 (VBUS), J6.B4 (VBUS), J6.B9 (VBUS), U5.5 (VBUS); also elsewhere on the board
/USB_CONN_U/DM: U5.3 (I/O2); also elsewhere on the board
/USB_CONN_U/DP: U5.1 (I/O1); also elsewhere on the board
D+: J6.A6 (D+), J6.B6 (D+), U5.6 (I/O1); also elsewhere on the board
D-: J6.A7 (D-), J6.B7 (D-), U5.4 (I/O2); also elsewhere on the board
GND: C10.1, C11.1, J6.A1 (GND), J6.A12 (GND), J6.B1 (GND), J6.B12 (GND), J6.S1 (SHIELD), R10.2, R11.2, U5.2 (GND); also elsewhere on the board
unnamed: J6.A5 (CC1), R10.1
unnamed: J6.B5 (CC2), R11.1

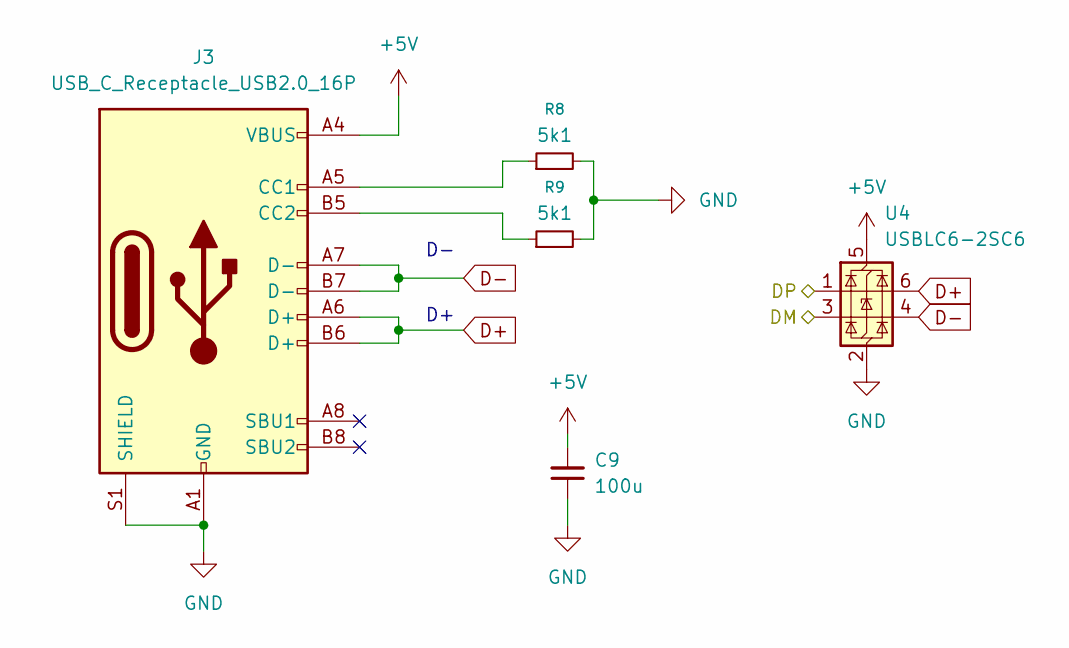
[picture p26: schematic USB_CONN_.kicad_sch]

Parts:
C9: 100u; C_1206_3216Metric; MPN KGM31HR50J107MU
J3: USB_C_Receptacle_USB2.0_16P; USB_C_Receptacle_Palconn_UTC16-G; MPN 217179-0001
R8, R9: 5k1; R_0603_1608Metric; MPN TNPW06035K11BYEN
U4: USBLC6-2SC6; SOT-23-6; MPN USBLC6-2SC6

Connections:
+5V: C9.2, J3.A4 (VBUS), J3.A9 (VBUS), J3.B4 (VBUS), J3.B9 (VBUS), U4.5 (VBUS); also elsewhere on the board
/USB_CONN_4/DM: U4.3 (I/O2); also elsewhere on the board
/USB_CONN_4/DP: U4.1 (I/O1); also elsewhere on the board
D+: J3.A6 (D+), J3.B6 (D+), U4.6 (I/O1); also elsewhere on the board
D-: J3.A7 (D-), J3.B7 (D-), U4.4 (I/O2); also elsewhere on the board
GND: C9.1, J3.A1 (GND), J3.A12 (GND), J3.B1 (GND), J3.B12 (GND), J3.S1 (SHIELD), R8.2, R9.2, U4.2 (GND); also elsewhere on the board
unnamed: J3.A5 (CC1), R8.1
unnamed: J3.B5 (CC2), R9.1

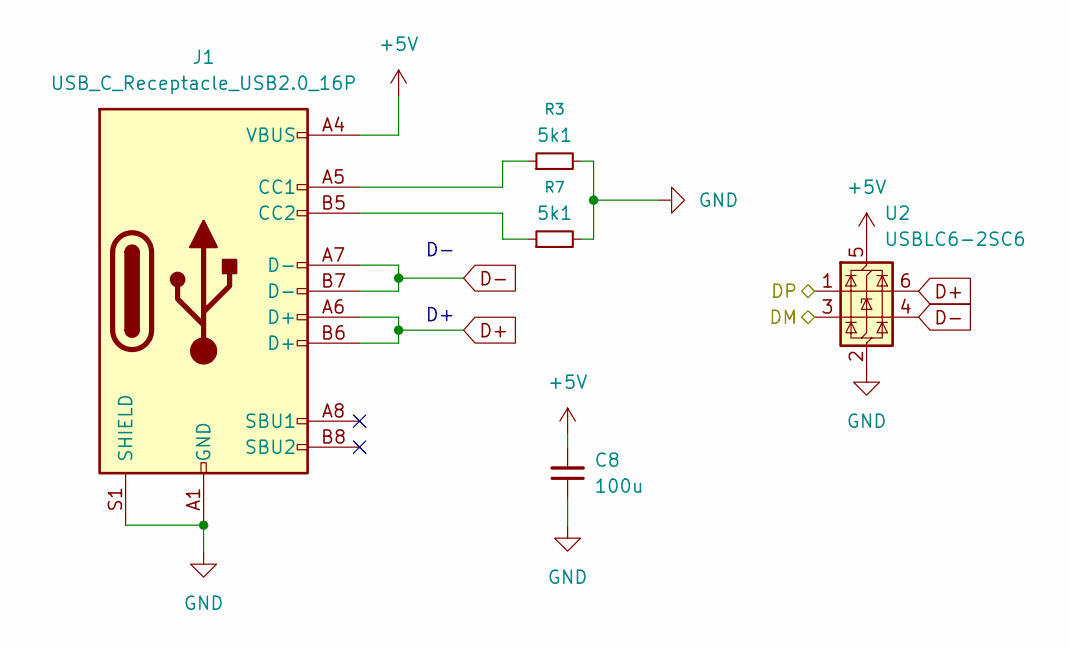
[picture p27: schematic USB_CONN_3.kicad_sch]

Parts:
C8: 100u; C_1206_3216Metric; MPN KGM31HR50J107MU
J1: USB_C_Receptacle_USB2.0_16P; USB_C_Receptacle_Palconn_UTC16-G; MPN 217179-0001
R3, R7: 5k1; R_0603_1608Metric; MPN TNPW06035K11BYEN
U2: USBLC6-2SC6; SOT-23-6; MPN USBLC6-2SC6

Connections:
+5V: C8.2, J1.A4 (VBUS), J1.A9 (VBUS), J1.B4 (VBUS), J1.B9 (VBUS), U2.5 (VBUS); also elsewhere on the board
/USB_CONN_3/DM: U2.3 (I/O2); also elsewhere on the board
/USB_CONN_3/DP: U2.1 (I/O1); also elsewhere on the board
D+: J1.A6 (D+), J1.B6 (D+), U2.6 (I/O1); also elsewhere on the board
D-: J1.A7 (D-), J1.B7 (D-), U2.4 (I/O2); also elsewhere on the board
GND: C8.1, J1.A1 (GND), J1.A12 (GND), J1.B1 (GND), J1.B12 (GND), J1.S1 (SHIELD), R3.2, R7.2, U2.2 (GND); also elsewhere on the board
unnamed: J1.A5 (CC1), R3.1
unnamed: J1.B5 (CC2), R7.1

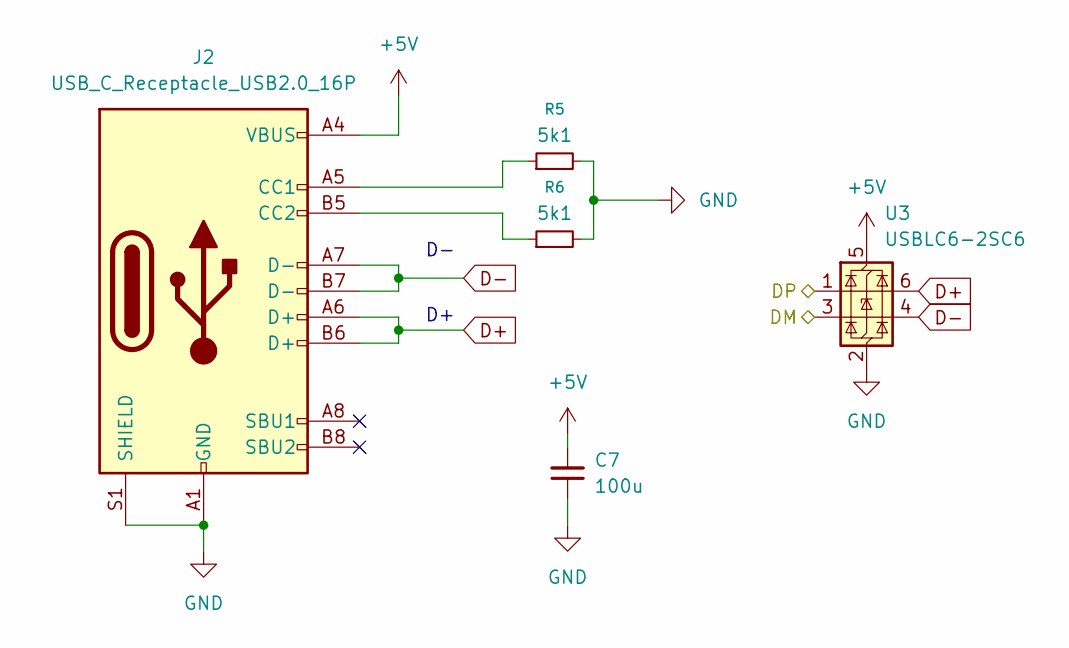
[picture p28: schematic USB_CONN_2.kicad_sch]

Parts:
C7: 100u; C_1206_3216Metric; MPN KGM31HR50J107MU
J2: USB_C_Receptacle_USB2.0_16P; USB_C_Receptacle_Palconn_UTC16-G; MPN 217179-0001
R5, R6: 5k1; R_0603_1608Metric; MPN TNPW06035K11BYEN
U3: USBLC6-2SC6; SOT-23-6; MPN USBLC6-2SC6

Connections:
+5V: C7.2, J2.A4 (VBUS), J2.A9 (VBUS), J2.B4 (VBUS), J2.B9 (VBUS), U3.5 (VBUS); also elsewhere on the board
/USB_CONN_2/DM: U3.3 (I/O2); also elsewhere on the board
/USB_CONN_2/DP: U3.1 (I/O1); also elsewhere on the board
D+: J2.A6 (D+), J2.B6 (D+), U3.6 (I/O1); also elsewhere on the board
D-: J2.A7 (D-), J2.B7 (D-), U3.4 (I/O2); also elsewhere on the board
GND: C7.1, J2.A1 (GND), J2.A12 (GND), J2.B1 (GND), J2.B12 (GND), J2.S1 (SHIELD), R5.2, R6.2, U3.2 (GND); also elsewhere on the board
unnamed: J2.A5 (CC1), R5.1
unnamed: J2.B5 (CC2), R6.1

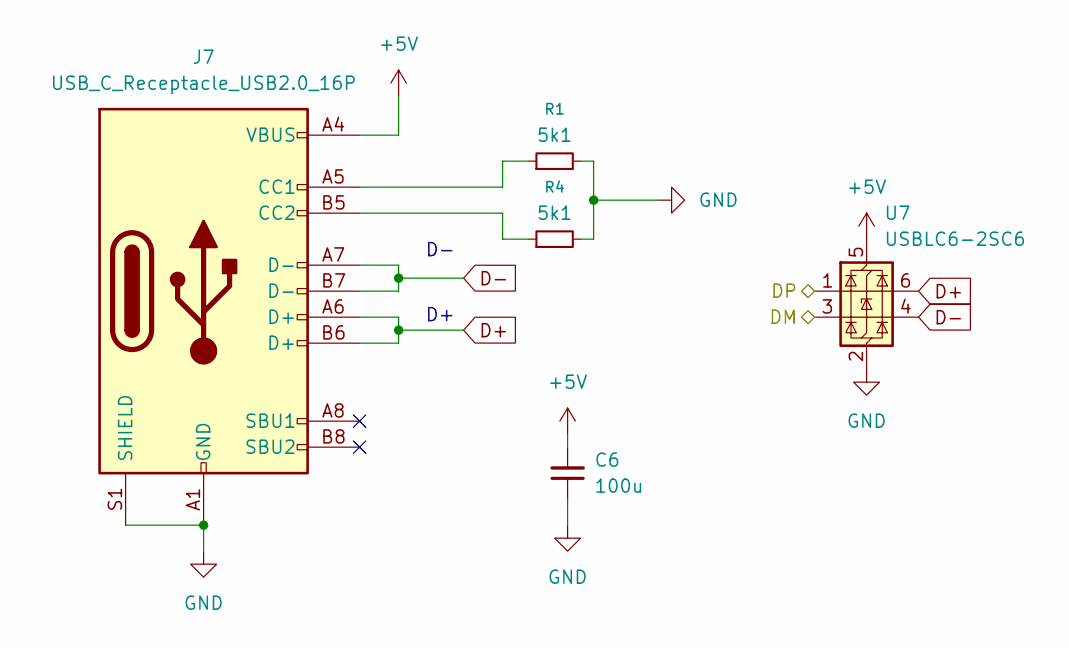
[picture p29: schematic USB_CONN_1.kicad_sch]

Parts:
C6: 100u; C_1206_3216Metric; MPN KGM31HR50J107MU
J7: USB_C_Receptacle_USB2.0_16P; USB_C_Receptacle_Palconn_UTC16-G; MPN 217179-0001
R1, R4: 5k1; R_0603_1608Metric; MPN TNPW06035K11BYEN
U7: USBLC6-2SC6; SOT-23-6; MPN USBLC6-2SC6

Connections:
+5V: C6.2, J7.A4 (VBUS), J7.A9 (VBUS), J7.B4 (VBUS), J7.B9 (VBUS), U7.5 (VBUS); also elsewhere on the board
/USB_CONN_1/DM: U7.3 (I/O2); also elsewhere on the board
/USB_CONN_1/DP: U7.1 (I/O1); also elsewhere on the board
D+: J7.A6 (D+), J7.B6 (D+), U7.6 (I/O1); also elsewhere on the board
D-: J7.A7 (D-), J7.B7 (D-), U7.4 (I/O2); also elsewhere on the board
GND: C6.1, J7.A1 (GND), J7.A12 (GND), J7.B1 (GND), J7.B12 (GND), J7.S1 (SHIELD), R1.2, R4.2, U7.2 (GND); also elsewhere on the board
unnamed: J7.A5 (CC1), R1.1
unnamed: J7.B5 (CC2), R4.1

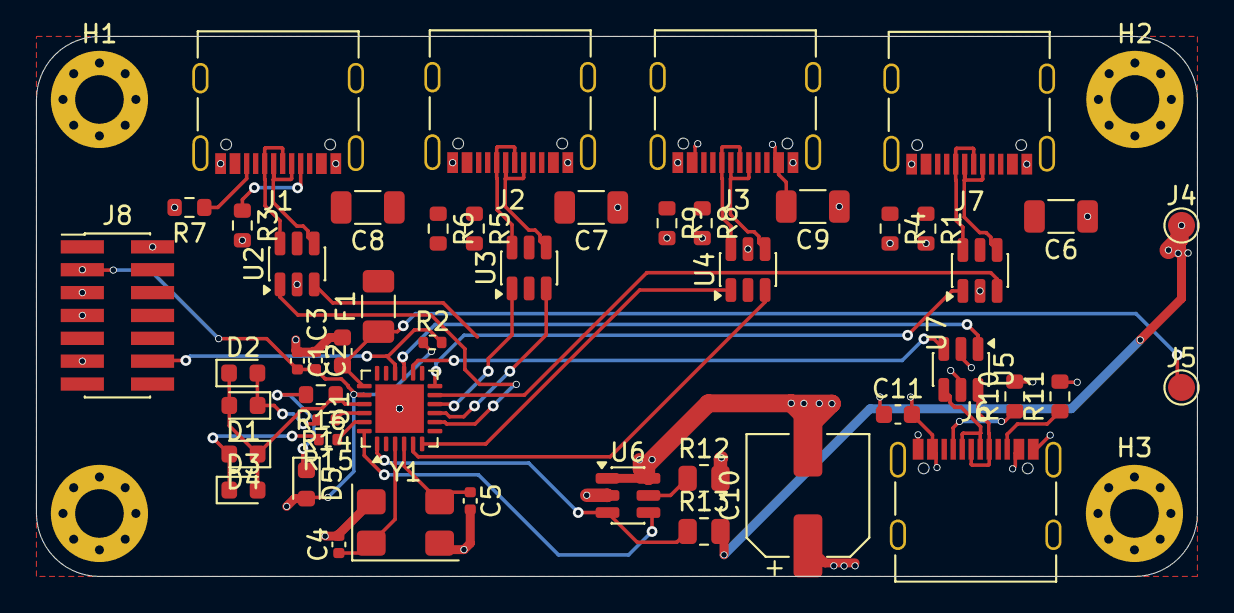
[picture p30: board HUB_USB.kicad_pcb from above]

Board: 4 copper layers, 64.5 x 30.0 mm, 53 parts (0 on the bottom side), 38 nets.

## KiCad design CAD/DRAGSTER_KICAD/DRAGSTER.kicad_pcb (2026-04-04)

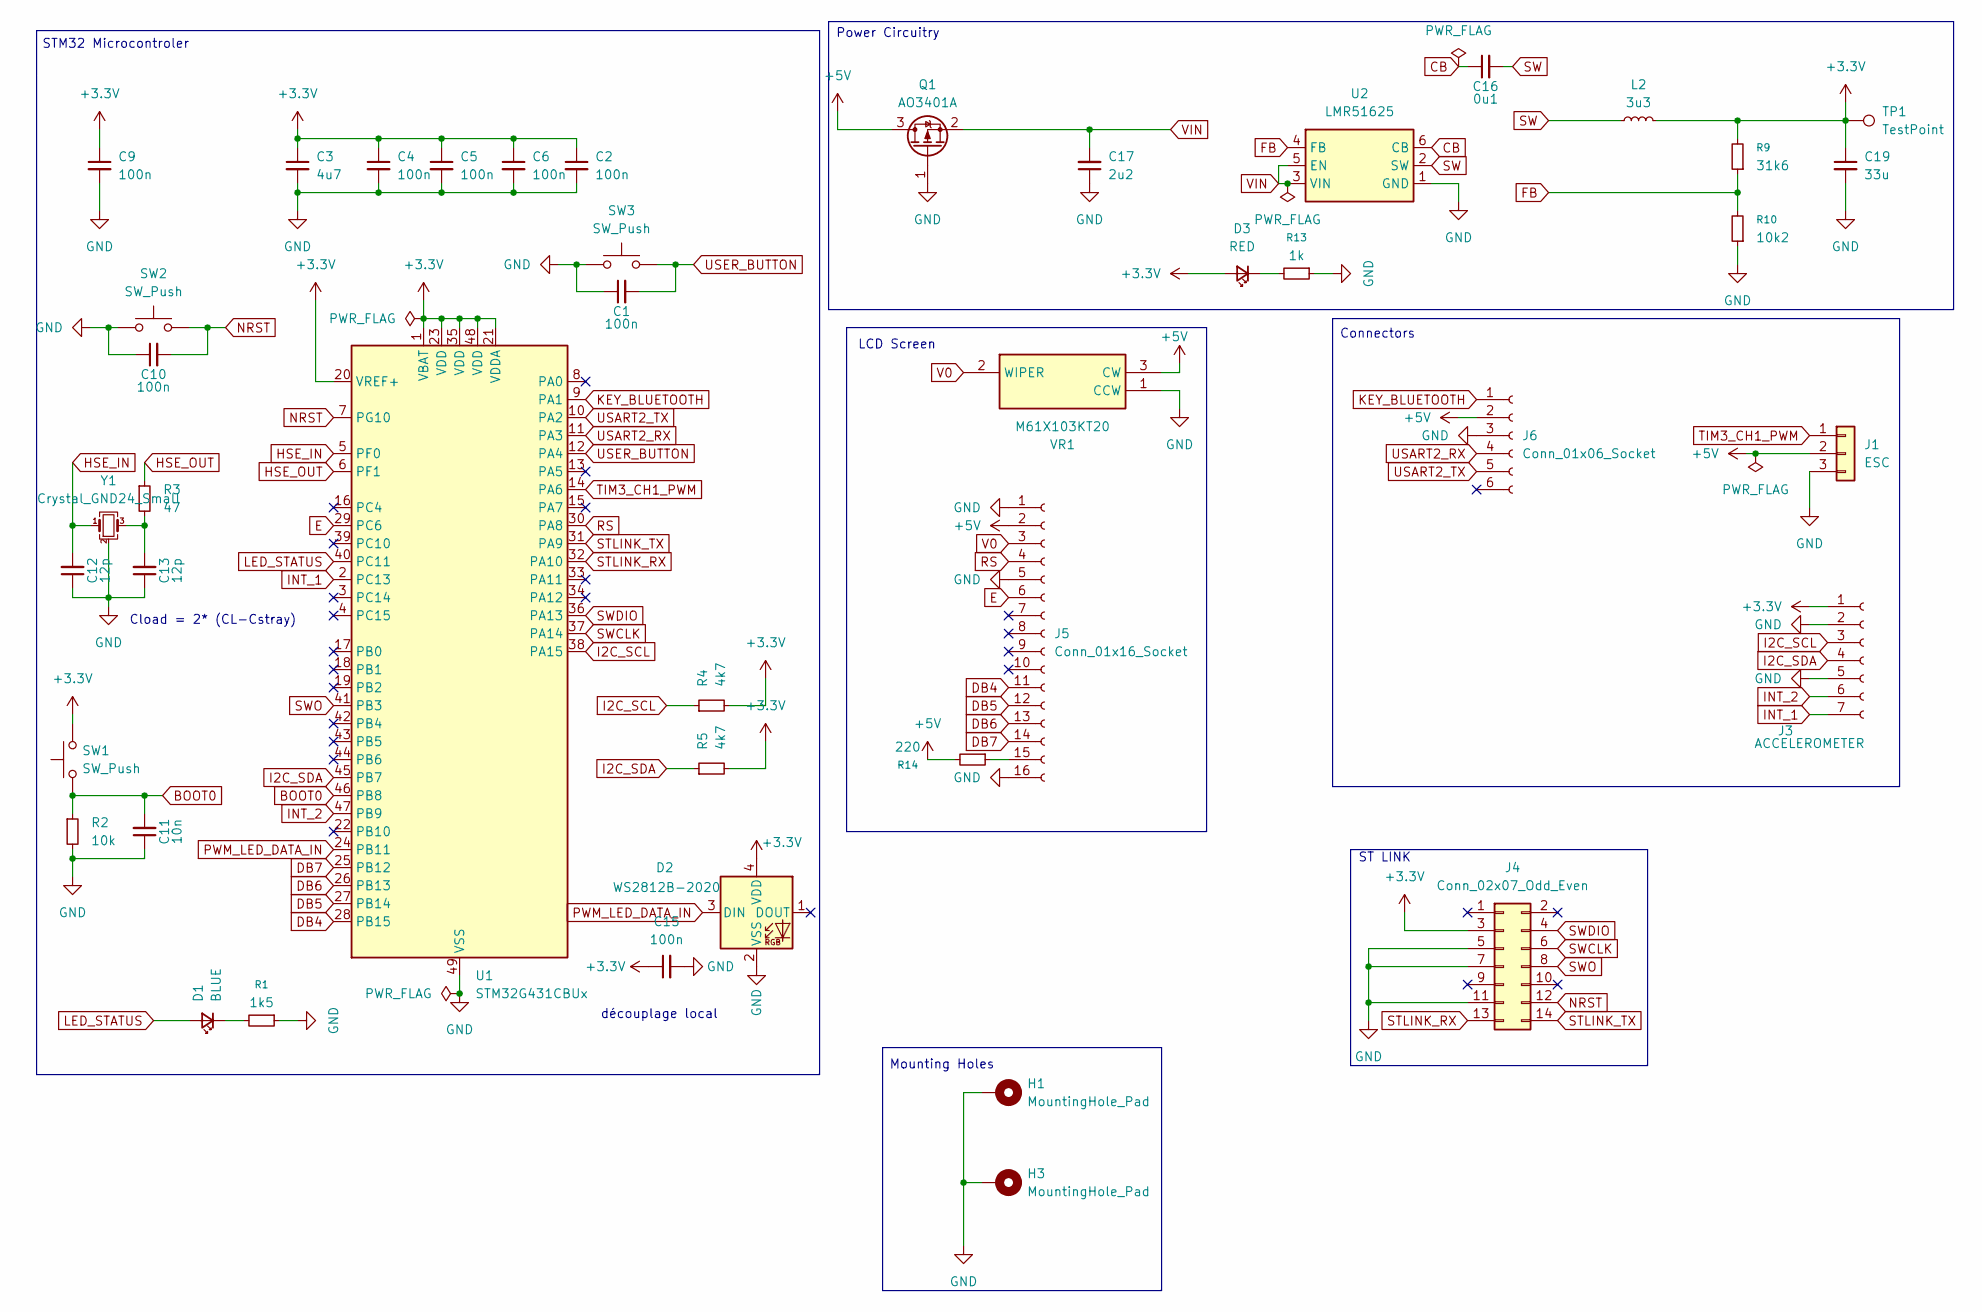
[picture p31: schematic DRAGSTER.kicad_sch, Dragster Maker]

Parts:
C1, C2, C4, C5, C6, C9, C10, C15: 100n; C_0402_1005Metric_Pad0.74x0.62mm_HandSolder; MPN 04026C104MAT2A
C3: 4u7; C_0402_1005Metric_Pad0.74x0.62mm_HandSolder; MPN MCASJ105BB5475MFNA1J
C11: 10n; C_0402_1005Metric_Pad0.74x0.62mm_HandSolder; MPN GRM155R70J103KA01D
C12, C13: 12p; C_0402_1005Metric_Pad0.74x0.62mm_HandSolder; MPN 0402YA120JAT2A
C16: 0u1; C_0603_1608Metric_Pad1.08x0.95mm_HandSolder; MPN CC0603KRX7R8BB104
C17: 2u2; C_1206_3216Metric_Pad1.33x1.80mm_HandSolder; MPN KGM31HR71C225KU
C19: 33u; C_2220_5750Metric_Pad1.97x5.40mm_HandSolder; MPN CKG57NX7R1C336M500JH
D1: BLUE; LED_0402_1005Metric_Pad0.77x0.64mm_HandSolder; MPN 599-1A90-147F
D2: WS2812B-2020; LED_WS2812B_PLCC4_5.0x5.0mm_P3.2mm; MPN 150044M155260
D3: RED; LED_0402_1005Metric_Pad0.77x0.64mm_HandSolder; MPN SML-P12UTT86R
H1, H3: MountingHole_Pad; MountingHole_4.3mm_M4_Pad_Via
J1: ESC; PinHeader_1x03_P1.27mm_Vertical
J3: ACCELEROMETER; PinSocket_1x07_P2.00mm_Vertical
J4: Conn_02x07_Odd_Even; FTSH-107-XX-YYY-DV-K
J5: Conn_01x16_Socket; PinSocket_1x16_P2.54mm_Vertical
J6: Conn_01x06_Socket; PinSocket_1x06_P2.54mm_Horizontal
L2: 3u3; 78439369033; MPN 78439369033
Q1: AO3401A; SOT-23; MPN SQ2389CES-T1_GE3
R1: 1k5; R_0402_1005Metric_Pad0.72x0.64mm_HandSolder; MPN 4D02WGJ0152TCE
R2: 10k; R_0402_1005Metric_Pad0.72x0.64mm_HandSolder; MPN 4D02WGF1002TCE
R3: 47; R_0402_1005Metric_Pad0.72x0.64mm_HandSolder; MPN 4D02WGF470JTCE
R4, R5: 4k7; R_0402_1005Metric_Pad0.72x0.64mm_HandSolder; MPN RT0402DRE074K7L
R9: 31k6; R_0402_1005Metric_Pad0.72x0.64mm_HandSolder; MPN CRT0402-BY-3162GLF
R10: 10k2; R_0402_1005Metric_Pad0.72x0.64mm_HandSolder; MPN ERA-2VPB1022X
R13: 1k; R_0402_1005Metric_Pad0.72x0.64mm_HandSolder; MPN RC0402JR-7D1KL
R14: 220; R_0402_1005Metric_Pad0.72x0.64mm_HandSolder; MPN ERA-2ARB221X
SW1, SW2, SW3: SW_Push; 15715636; MPN 1571563-6
TP1: TestPoint; TestPoint_Pad_1.5x1.5mm
U1: STM32G431CBUx; QFN-48-1EP_7x7mm_P0.5mm_EP5.6x5.6mm; MPN STM32G431CBU6
U2: LMR51625; SOT-23-6; MPN LMR51625XDDCR
VR1: M61X103KT20; Manufacturer_Part_Number M61X103KT20
Y1: Crystal_GND24_Small; LFXTAL071744Reel; MPN LFXTAL071744Reel

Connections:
+3.3V: C2.1, C3.1, C4.1, C5.1, C6.1, C9.1, C15.1, C19.1, D2.4 (VDD), D3.2 (A), J3.1, J4.3, L2.2, R4.2, R5.2, R9.2, SW1.2, TP1.1, U1.1 (VBAT), U1.20 (VREF+), U1.21 (VDDA), U1.23 (VDD), U1.35 (VDD), U1.48 (VDD); also elsewhere on the board
+5V: J1.2, J5.2, J6.2, Q1.3 (D), R14.2, VR1.3 (CW)
BOOT0: C11.2, R2.1, SW1.1, U1.46 (PB8)
CB: C16.1, U2.6 (CB)
DB4: J5.11, U1.28 (PB15)
DB5: J5.12, U1.27 (PB14)
DB6: J5.13, U1.26 (PB13)
DB7: J5.14, U1.25 (PB12)
E: J5.6, U1.29 (PC6)
FB: R9.1, R10.2, U2.4 (FB)
GND: C1.1, C2.2, C3.2, C4.2, C5.2, C6.2, C9.2, C10.1, C11.1, C12.1, C13.1, C15.2, C17.1, C19.2, D2.2 (VSS), H1.1, H3.1, J1.3, J3.2, J3.5, J4.5, J4.7, J4.11, J5.1, J5.5, J5.16, J6.3, Q1.1 (G), R1.1, R2.2, R10.1, R13.1, SW2.1, SW3.1, U1.49 (VSS), U2.1 (GND), VR1.1 (CCW), Y1.2 (G), Y1.4 (G); also elsewhere on the board
HSE_IN: C12.2, U1.5 (PF0), Y1.1
HSE_OUT: R3.1, U1.6 (PF1)
I2C_SCL: J3.3, R4.1, U1.38 (PA15)
I2C_SDA: J3.4, R5.1, U1.45 (PB7)
INT_1: J3.7, U1.2 (PC13)
INT_2: J3.6, U1.47 (PB9)
KEY_BLUETOOTH: J6.1, U1.9 (PA1)
LED_STATUS: D1.2 (A), U1.40 (PC11)
NRST: C10.2, J4.12, SW2.2, U1.7 (PG10)
unnamed: C13.2, R3.2, Y1.3
unnamed: D1.1 (K), R1.2
unnamed: D3.1 (K), R13.2
unnamed: J5.15, R14.1
PWM_LED_DATA_IN: D2.3 (DIN), U1.24 (PB11)
RS: J5.4, U1.30 (PA8)
STLINK_RX: J4.13, U1.32 (PA10)
STLINK_TX: J4.14, U1.31 (PA9)
SW: C16.2, L2.1, U2.2 (SW)
SWCLK: J4.6, U1.37 (PA14)
SWDIO: J4.4, U1.36 (PA13)
SWO: J4.8, U1.41 (PB3)
TIM3_CH1_PWM: J1.1, U1.14 (PA6)
USART2_RX: J6.4, U1.11 (PA3)
USART2_TX: J6.5, U1.10 (PA2)
USER_BUTTON: C1.2, SW3.2, U1.12 (PA4)
V0: J5.3, VR1.2 (WIPER)
VIN: C17.2, Q1.2 (S), U2.3 (VIN), U2.5 (EN)

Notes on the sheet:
STM32 Microcontroler
LCD Screen
Connectors
découplage local
Mounting Holes
Power Circuitry
Cload = 2* (CL-Cstray)
ST LINK

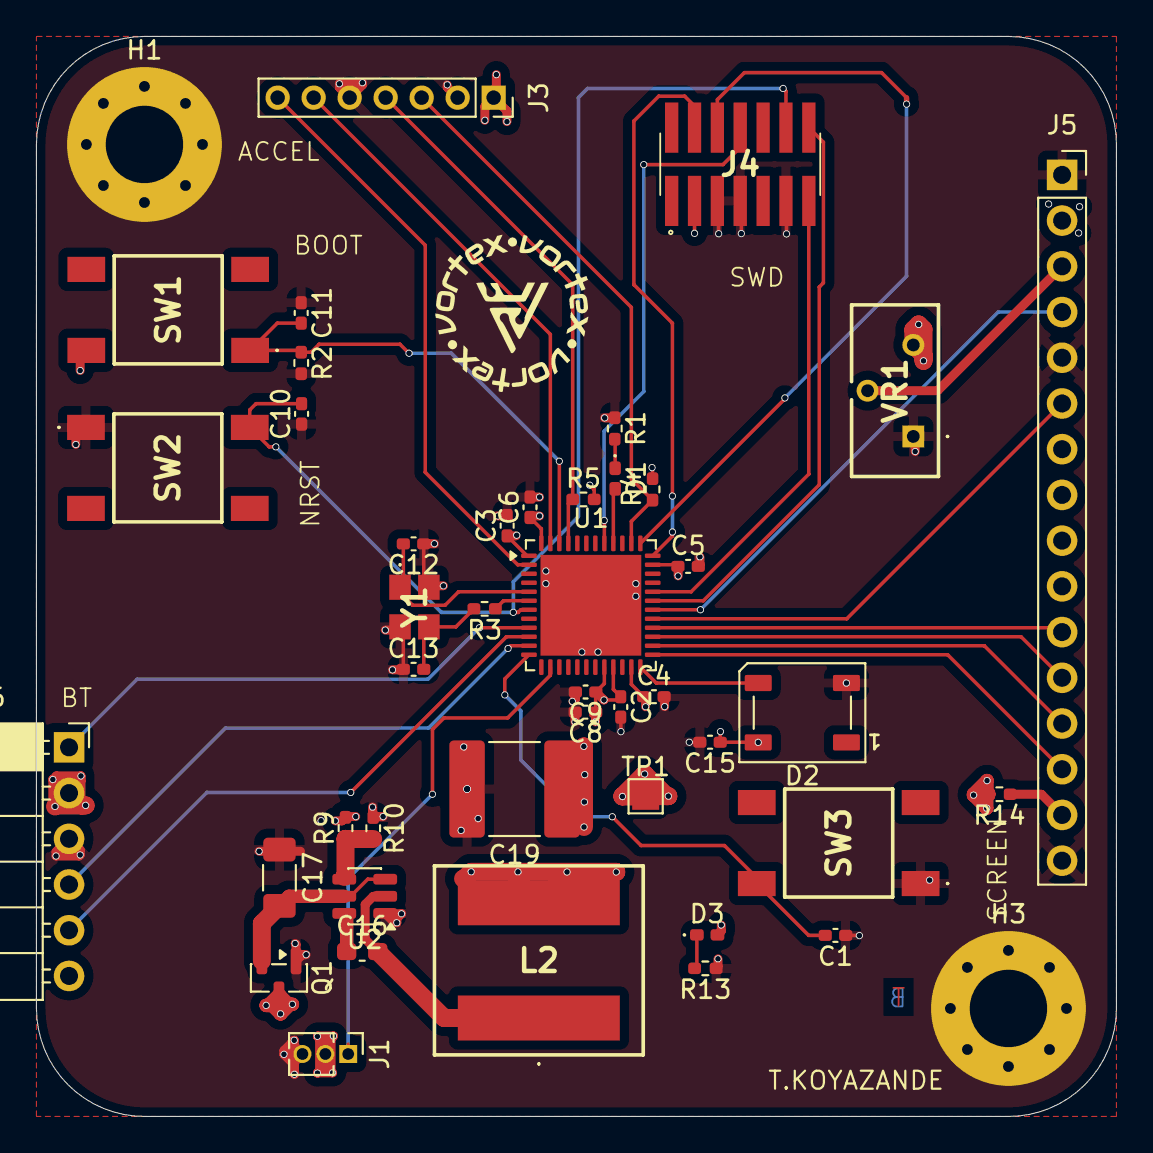
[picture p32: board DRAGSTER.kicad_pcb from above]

Board: 4 copper layers, 60.0 x 60.0 mm, 45 parts (0 on the bottom side), 38 nets.

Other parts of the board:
C8: 1u; C_0402_1005Metric_Pad0.74x0.62mm_HandSolder

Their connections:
+3.3V: C8.1; also elsewhere on the board
GND: C8.2; also elsewhere on the board

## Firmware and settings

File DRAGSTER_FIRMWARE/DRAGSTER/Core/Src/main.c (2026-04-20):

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
/* Includes ------------------------------------------------------------------*/
#include "main.h"
#include "dma.h"
#include "i2c.h"
#include "tim.h"
#include "usart.h"
#include "gpio.h"

/* USER CODE BEGIN Includes */
#include "hc05_bt.h"
#include "mma8452q.h"
#include "tc1602a_lcd.h"
#include <stdio.h>
#include <string.h>
#include "bldc_esc.h"
#include "ws2812.h"
/* USER CODE END Includes */


/* USER CODE BEGIN PV */
MMA8452Q_Handle_t accel = { .hi2c=&hi2c1, .i2c_addr=MMA8452Q_I2C_ADDR,
                             .range=MMA8452Q_RANGE_8G, .odr=MMA8452Q_ODR_800HZ };
BT_Handle_t bt;
ESC_Handle_t esc;              /* add this */
/* USER CODE END PV */

void SystemClock_Config(void);
/**
  * @brief  The application entry point.
  * @retval int
  */
int main(void)
{

  /* USER CODE BEGIN 1 */
	/* Force PA6 LOW before ESC boots — same as holding reset on Nucleo */
//	__HAL_RCC_GPIOA_CLK_ENABLE();
//	GPIOA->MODER  &= ~(3U << (6*2));
//	GPIOA->MODER  |=  (1U << (6*2));
//	GPIOA->BSRR    =  (1U << (6+16));
  /* USER CODE END 1 */

  /* MCU Configuration--------------------------------------------------------*/

  /* Reset of all peripherals, Initializes the Flash interface and the Systick. */
  HAL_Init();

  /* Configure the system clock */
  SystemClock_Config();

  /* Initialize all configured peripherals */
  MX_GPIO_Init();
  MX_DMA_Init();
  MX_I2C1_Init();
  MX_TIM2_Init();
  MX_TIM3_Init();
  HAL_TIM_PWM_Start(&htim3, TIM_CHANNEL_1);  /* ← is this line still there? */
  __HAL_TIM_SET_COMPARE(&htim3, TIM_CHANNEL_1, 199);
  MX_USART1_UART_Init();
  MX_USART2_UART_Init();
  /* USER CODE BEGIN 2 */
  /* --- Bare minimum LCD init test --- */
//  #define LCD_RS_LOW()   HAL_GPIO_WritePin(GPIOA, GPIO_PIN_8,  GPIO_PIN_RESET)
//  #define LCD_RS_HIGH()  HAL_GPIO_WritePin(GPIOA, GPIO_PIN_8,  GPIO_PIN_SET)
//  #define LCD_E_LOW()    HAL_GPIO_WritePin(GPIOC, GPIO_PIN_6,  GPIO_PIN_RESET)
//  #define LCD_E_HIGH()   HAL_GPIO_WritePin(GPIOC, GPIO_PIN_6,  GPIO_PIN_SET)
//
//  #define LCD_D4(x) HAL_GPIO_WritePin(GPIOB, GPIO_PIN_15, x ? GPIO_PIN_SET : GPIO_PIN_RESET)
//  #define LCD_D5(x) HAL_GPIO_WritePin(GPIOB, GPIO_PIN_14, x ? GPIO_PIN_SET : GPIO_PIN_RESET)
//  #define LCD_D6(x) HAL_GPIO_WritePin(GPIOB, GPIO_PIN_13, x ? GPIO_PIN_SET : GPIO_PIN_RESET)
//  #define LCD_D7(x) HAL_GPIO_WritePin(GPIOB, GPIO_PIN_12, x ? GPIO_PIN_SET : GPIO_PIN_RESET)
//
//  /* Pulse Enable */
//  #define LCD_PULSE() do { LCD_E_HIGH(); HAL_Delay(2); LCD_E_LOW(); HAL_Delay(2); } while(0)
//
//  /* Send nibble (4 bits) */
//  #define LCD_NIBBLE(n) do {
//      LCD_D4(((n) >> 0) & 1);
//      LCD_D5(((n) >> 1) & 1);
//      LCD_D6(((n) >> 2) & 1);
//      LCD_D7(((n) >> 3) & 1);
//      LCD_PULSE();
//  } while(0)
//
//  /* Send full byte as two nibbles */
//  #define LCD_CMD(b)  do { LCD_RS_LOW();  LCD_NIBBLE((b)>>4); LCD_NIBBLE((b)&0xF); HAL_Delay(2); } while(0)
//  #define LCD_DATA(b) do { LCD_RS_HIGH(); LCD_NIBBLE((b)>>4); LCD_NIBBLE((b)&0xF); HAL_Delay(2); } while(0)
//
//  /* Power on delay */
//  HAL_Delay(100);
//  LCD_E_LOW();
//  LCD_RS_LOW();
//
//  /* Init sequence — 3× send 0x3 then switch to 4-bit */
//  LCD_D4(1); LCD_D5(1); LCD_D6(0); LCD_D7(0);
//  LCD_PULSE(); HAL_Delay(10);
//  LCD_PULSE(); HAL_Delay(5);
//  LCD_PULSE(); HAL_Delay(2);
//
//  /* Switch to 4-bit */
//  LCD_D4(0); LCD_D5(1); LCD_D6(0); LCD_D7(0);
//  LCD_PULSE(); HAL_Delay(2);
//
//  /* Function set: 4-bit, 2 lines, 5x8 */
//  LCD_CMD(0x28);
//  /* Display on, cursor off */
//  LCD_CMD(0x0C);
//  /* Clear */
//  LCD_CMD(0x01); HAL_Delay(5);
//  /* Entry mode */
//  LCD_CMD(0x06);
//
//  /* Print "HELLO" */
//  LCD_DATA('H');
//  LCD_DATA('E');
//  LCD_DATA('L');
//  LCD_DATA('L');
//  LCD_DATA('O');

  /* I2C bus scan — finds all responding devices */
//  char dbg[50];
//  HAL_UART_Transmit(&huart1, (uint8_t*)"I2C SCAN:\r\n", 11, 100);
//  for (uint8_t addr = 0x08; addr < 0x78; addr++)
//  {
//      if (HAL_I2C_IsDeviceReady(&hi2c1, addr << 1, 1, 10) == HAL_OK)
//      {
//          snprintf(dbg, sizeof(dbg), "  Found device at 0x%02X\r\n", addr);
//          HAL_UART_Transmit(&huart1, (uint8_t*)dbg, strlen(dbg), 100);
//      }
//  }
//  HAL_UART_Transmit(&huart1, (uint8_t*)"SCAN DONE\r\n", 11, 100);
//
//  /* Using HAL_I2C_Mem_Read — handles repeated start automatically */
//  uint8_t who = 0;
//  HAL_StatusTypeDef r = HAL_I2C_Mem_Read(&hi2c1,
//                                           0x1C << 1,  /* device address */
//                                           0x0D,        /* WHO_AM_I register */
//                                           I2C_MEMADD_SIZE_8BIT,
//                                           &who, 1, 100);
//
//  snprintf(dbg, sizeof(dbg), "MEM_READ=%d WHO=0x%02X\r\n", r, who);
//  HAL_UART_Transmit(&huart1, (uint8_t*)dbg, strlen(dbg), 100);
//
//  /* Temporary accelerometer diagnosis */
//  MMA8452Q_Status_t accel_status = MMA8452Q_Init(&accel);
//
//  snprintf(dbg, sizeof(dbg), "ACCEL INIT: %s\r\n",
//           accel_status == MMA8452Q_OK ? "OK" : "FAILED");
//  HAL_UART_Transmit(&huart1, (uint8_t*)dbg, strlen(dbg), 100);
  WS2812_Init();
  WS2812_SetColor(0, 50, 0);  /* green */
  WS2812_Refresh();
  HAL_Delay(10);

  LCD_Splash();
  MMA8452Q_Init(&accel);
  BT_Init(&bt, &huart2, &huart1, &accel);
  HAL_Delay(1000);
  LCD_Clear();
  LCD_ResetSpeed();
  LCD_ShowStatus("Arming ESC...");
  ESC_Init(&esc, &htim3, TIM_CHANNEL_1);
  LCD_ShowStatus("ESC Ready!  ");
  HAL_Delay(1000);
  LCD_ShowStatus("                ");
  /* Raw ESC test — bypass all drivers */
//  HAL_TIM_PWM_Start(&htim3, TIM_CHANNEL_1);
//
//  __HAL_TIM_SET_COMPARE(&htim3, TIM_CHANNEL_1, 2999);
//  HAL_Delay(4000);
//
//  __HAL_TIM_SET_COMPARE(&htim3, TIM_CHANNEL_1, 199);
//  HAL_Delay(2000);
//
//  //__HAL_TIM_SET_COMPARE(&htim3, TIM_CHANNEL_1, 2999);
//  HAL_Delay(2000);



  /* USER CODE END 2 */

  /* Infinite loop */
  /* USER CODE BEGIN WHILE */
  while (1)
  {
	  //__HAL_TIM_SET_COMPARE(&htim3, TIM_CHANNEL_1, 999);

	  BT_Task(&bt);

	      if (MMA8452Q_IsDataReady(&accel))
	      {
	          float g = 0.0f;
	          if (MMA8452Q_ReadAccelX(&accel, &g) == MMA8452Q_OK)
	          {
	        	  LCD_IntegrateSpeed(g, 1.0f/800.0f);
	          }
	      }

    /* USER CODE END WHILE */

    /* USER CODE BEGIN 3 */
  }
  /* USER CODE END 3 */
}

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


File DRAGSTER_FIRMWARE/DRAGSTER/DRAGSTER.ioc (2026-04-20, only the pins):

Mcu.UserName=STM32G431CBUx
PA1.GPIO_Label=KEY
PA1.Signal=GPIO_Output
PA10.Signal=USART1_RX
PA13.Signal=SYS_JTMS-SWDIO
PA14.Signal=SYS_JTCK-SWCLK
PA15.Signal=I2C1_SCL
PA2.Signal=USART2_TX
PA3.Signal=USART2_RX
PA4.GPIO_Label=USER_BUTTON
PA4.Signal=GPIO_Input
PA6.Signal=S_TIM3_CH1
PA8.GPIO_Label=RS
PA8.Signal=GPIO_Output
PA9.Signal=USART1_TX
PB11.Signal=S_TIM2_CH4
PB12.GPIO_Label=DB7
PB12.Signal=GPIO_Output
PB13.GPIO_Label=DB6
PB13.Signal=GPIO_Output
PB14.GPIO_Label=DB5
PB14.Signal=GPIO_Output
PB15.GPIO_Label=DB4
PB15.Signal=GPIO_Output
PB3.Signal=SYS_JTDO-SWO
PB7.Signal=I2C1_SDA
PB9.GPIO_Label=INT_2
PB9.Signal=GPIO_Input
PC11.GPIO_Label=BLUE_USER_LED
PC11.Signal=GPIO_Output
PC13.GPIO_Label=INT_1
PC13.Signal=GPIO_Input
PC6.GPIO_Label=E
PC6.Signal=GPIO_Output
PF0-OSC_IN.Signal=RCC_OSC_IN
PF1-OSC_OUT.Signal=RCC_OSC_OUT

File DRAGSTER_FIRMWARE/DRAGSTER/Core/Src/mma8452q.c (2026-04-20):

/**
 * @file    mma8452q.c
 * @brief   Driver for MMA8452Q 3-axis accelerometer — X-axis only (Dragster project)
 * @target  STM32G431CBU6 — I2C1 (SCL: PA15 / SDA: PB7)
 *
 * Wiring reminder:
 *   VCC  → 3.3 V
 *   GND  → GND
 *   SCL  → PA15  (I2C1_SCL)
 *   SDA  → PB7   (I2C1_SDA)
 *   INT1 → PC13  (GPIO_Input, label INT_1)
 *   INT2 → PB9   (GPIO_Input, label INT_2)
 *   SA0  → GND   → I2C address 0x1C  (change MMA8452Q_I2C_ADDR if tied to VCC)
 */

#include "mma8452q.h"

/* -------------------------------------------------------------------------
 * I2C timeout (ms)
 * ------------------------------------------------------------------------- */
#define I2C_TIMEOUT_MS   10U

/* -------------------------------------------------------------------------
 * STATUS register bit
 * ------------------------------------------------------------------------- */
#define STATUS_XYZDR     0x08   /*!< Any-axis data-ready flag */
#define STATUS_XDR       0x01   /*!< X-axis data-ready flag   */

/* -------------------------------------------------------------------------
 * CTRL_REG2 — software reset bit
 * ------------------------------------------------------------------------- */
#define CTRL_REG2_RST    0x40

/* -------------------------------------------------------------------------
 * Private helpers
 * ------------------------------------------------------------------------- */

/**
 * @brief Write a single byte to a register.
 */
static MMA8452Q_Status_t prv_WriteReg(MMA8452Q_Handle_t *dev,
                                       uint8_t reg,
                                       uint8_t value)
{
    uint8_t buf[2] = { reg, value };
    if (HAL_I2C_Master_Transmit(dev->hi2c,
                                dev->i2c_addr,
                                buf, 2,
                                I2C_TIMEOUT_MS) != HAL_OK)
    {
        return MMA8452Q_ERROR;
    }
    return MMA8452Q_OK;
}

/**
 * @brief Read one or more bytes starting at a register.
 */
static MMA8452Q_Status_t prv_ReadRegs(MMA8452Q_Handle_t *dev,
                                       uint8_t reg,
                                       uint8_t *data,
                                       uint16_t len)
{
    if (HAL_I2C_Mem_Read(dev->hi2c,
                         dev->i2c_addr,
                         reg,
                         I2C_MEMADD_SIZE_8BIT,
                         data, len,
                         10U) != HAL_OK)
    {
        return MMA8452Q_ERROR;
    }
    return MMA8452Q_OK;
}

/**
 * @brief Compute the sensitivity factor (g per LSB) from the chosen range.
 *        The MMA8452Q outputs 12-bit signed values (right-aligned after shift).
 *        Full scale counts = 2^11 = 2048 for one side.
 */
static float prv_ComputeSensitivity(MMA8452Q_Range_t range)
{
    switch (range)
    {
        case MMA8452Q_RANGE_4G: return 4.0f  / 2048.0f;
        case MMA8452Q_RANGE_8G: return 8.0f  / 2048.0f;
        case MMA8452Q_RANGE_2G:
        default:                return 2.0f  / 2048.0f;
    }
}

/* -------------------------------------------------------------------------
 * Public API implementation
 * ------------------------------------------------------------------------- */

MMA8452Q_Status_t MMA8452Q_Init(MMA8452Q_Handle_t *dev)
{
    uint8_t who_am_i = 0;

    /* --- 1. Verify device identity ---------------------------------------- */
    if (prv_ReadRegs(dev, MMA8452Q_REG_WHO_AM_I, &who_am_i, 1) != MMA8452Q_OK)
    {
        return MMA8452Q_ERROR;
    }
    if (who_am_i != MMA8452Q_WHO_AM_I_VALUE)
    {
        return MMA8452Q_ERROR;   /* Wrong device or wiring issue */
    }

    /* --- 2. Software reset ------------------------------------------------- */
    if (MMA8452Q_Reset(dev) != MMA8452Q_OK)
    {
        return MMA8452Q_ERROR;
    }

    /* --- 3. Go to standby before changing configuration ------------------- */
    if (MMA8452Q_Standby(dev) != MMA8452Q_OK)
    {
        return MMA8452Q_ERROR;
    }

    /* --- 4. Set full-scale range ------------------------------------------ */
    /*
     * XYZ_DATA_CFG[1:0] → FS[1:0]
     * No high-pass filter on output data (HPF_OUT = 0).
     */
    if (prv_WriteReg(dev, MMA8452Q_REG_XYZ_DATA_CFG,
                     (uint8_t)dev->range) != MMA8452Q_OK)
    {
        return MMA8452Q_ERROR;
    }

    /* --- 5. Set output data rate & low-noise mode ------------------------- */
    /*
     * CTRL_REG1:
     *   LNOISE (bit 2) = 1 → low-noise mode (not available with ±8 g range)
     *   DR[2:0] (bits [5:3]) = selected ODR
     *   ACTIVE (bit 0) = 0 → remain in standby for now
     *
     * For a dragster (high-g transient event) 800 Hz or 400 Hz is recommended.
     */
    uint8_t ctrl1 = (uint8_t)dev->odr;
    if (dev->range != MMA8452Q_RANGE_8G)
    {
        ctrl1 |= 0x04;  /* LNOISE bit — disabled automatically at ±8 g */
    }
    if (prv_WriteReg(dev, MMA8452Q_REG_CTRL_REG1, ctrl1) != MMA8452Q_OK)
    {
        return MMA8452Q_ERROR;
    }

    /* --- 6. Store sensitivity for g conversion --------------------------- */
    dev->sensitivity = prv_ComputeSensitivity(dev->range);

    /* --- 7. Activate ------------------------------------------------------- */
    if (MMA8452Q_Active(dev) != MMA8452Q_OK)
    {
        return MMA8452Q_ERROR;
    }

    return MMA8452Q_OK;
}

/* -------------------------------------------------------------------------- */

MMA8452Q_Status_t MMA8452Q_ReadRawX(MMA8452Q_Handle_t *dev, int16_t *raw_x)
{
    uint8_t buf[2];

    /* Read OUT_X_MSB and OUT_X_LSB in a single 2-byte burst */
    if (prv_ReadRegs(dev, MMA8452Q_REG_OUT_X_MSB, buf, 2) != MMA8452Q_OK)
    {
        return MMA8452Q_ERROR;
    }

    /*
     * The MMA8452Q delivers 12-bit data left-justified in the 16-bit word:
     *   MSB[7:0] = bits [11:4] of the measurement
     *   LSB[7:4] = bits [3:0]  of the measurement
     *   LSB[3:0] = 0 (unused)
     *
     * Reconstruct the signed 12-bit value:
     *   1. Combine bytes into a 16-bit value  (MSB << 8 | LSB)
     *   2. Arithmetic right-shift by 4 to get 12-bit signed integer
     */
    int16_t raw = (int16_t)((buf[0] << 8) | buf[1]);
    raw >>= 4;      /* Sign-extending arithmetic shift */

    *raw_x = raw;
    return MMA8452Q_OK;
}

/* -------------------------------------------------------------------------- */

MMA8452Q_Status_t MMA8452Q_ReadAccelX(MMA8452Q_Handle_t *dev, float *accel_g)
{
    int16_t raw = 0;

    if (MMA8452Q_ReadRawX(dev, &raw) != MMA8452Q_OK)
    {
        return MMA8452Q_ERROR;
    }

    *accel_g = (float)raw * dev->sensitivity;
    return MMA8452Q_OK;
}

/* -------------------------------------------------------------------------- */

bool MMA8452Q_IsDataReady(MMA8452Q_Handle_t *dev)
{
    uint8_t status = 0;

    if (prv_ReadRegs(dev, MMA8452Q_REG_STATUS, &status, 1) != MMA8452Q_OK)
    {
        return false;
    }

    /* XDR bit (bit 0) — X-axis new data available */
    return (status & STATUS_XDR) != 0;
}
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

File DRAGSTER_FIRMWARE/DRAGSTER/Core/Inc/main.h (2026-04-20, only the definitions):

#define INT_1_Pin GPIO_PIN_13
#define INT_1_GPIO_Port GPIOC
#define KEY_Pin GPIO_PIN_1
#define KEY_GPIO_Port GPIOA
#define USER_BUTTON_Pin GPIO_PIN_4
#define USER_BUTTON_GPIO_Port GPIOA
#define DB7_Pin GPIO_PIN_12
#define DB7_GPIO_Port GPIOB
#define DB6_Pin GPIO_PIN_13
#define DB6_GPIO_Port GPIOB
#define DB5_Pin GPIO_PIN_14
#define DB5_GPIO_Port GPIOB
#define DB4_Pin GPIO_PIN_15
#define DB4_GPIO_Port GPIOB
#define E_Pin GPIO_PIN_6
#define E_GPIO_Port GPIOC
#define RS_Pin GPIO_PIN_8
#define RS_GPIO_Port GPIOA
#define BLUE_USER_LED_Pin GPIO_PIN_11
#define BLUE_USER_LED_GPIO_Port GPIOC
#define INT_2_Pin GPIO_PIN_9
#define INT_2_GPIO_Port GPIOB

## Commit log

2026-02-26 uploaded cubeMX ioc file & pcb
    [DRAGSTER.csv, DRAGSTER.kicad_pcb, DRAGSTER.kicad_sch]
2026-03-04 updated pcb
    [DRAGSTER.kicad_pcb]
2026-04-04 reshuffled stuffs a bit
    [Corps.stl, DRAGSTER.csv, DRAGSTER.kicad_pcb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]
2026-04-20 final update
    [Guide_Roues.stl]
2026-04-28 added kicad bom file
    [Corps.stl, DRAGSTER.kicad_pcb, DRAGSTER.kicad_sch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]
2026-05-05 uploaded TD
    [Drawing_Useless_Box.dxf, Exercice 1.stl, Exercice 2.stl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]

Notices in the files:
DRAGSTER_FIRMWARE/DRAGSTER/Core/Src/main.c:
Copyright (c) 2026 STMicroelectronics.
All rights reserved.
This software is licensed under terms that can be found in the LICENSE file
